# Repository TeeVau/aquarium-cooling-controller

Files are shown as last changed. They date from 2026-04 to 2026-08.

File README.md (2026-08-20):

# Aquarium Cooling Controller








ESP32 firmware for autonomous aquarium cooling with a 4-pin PWM fan, one
DS18B20 water-temperature sensor, an optional local OLED status display, MQTT
telemetry, FHEM integration, and broker-driven OTA updates.

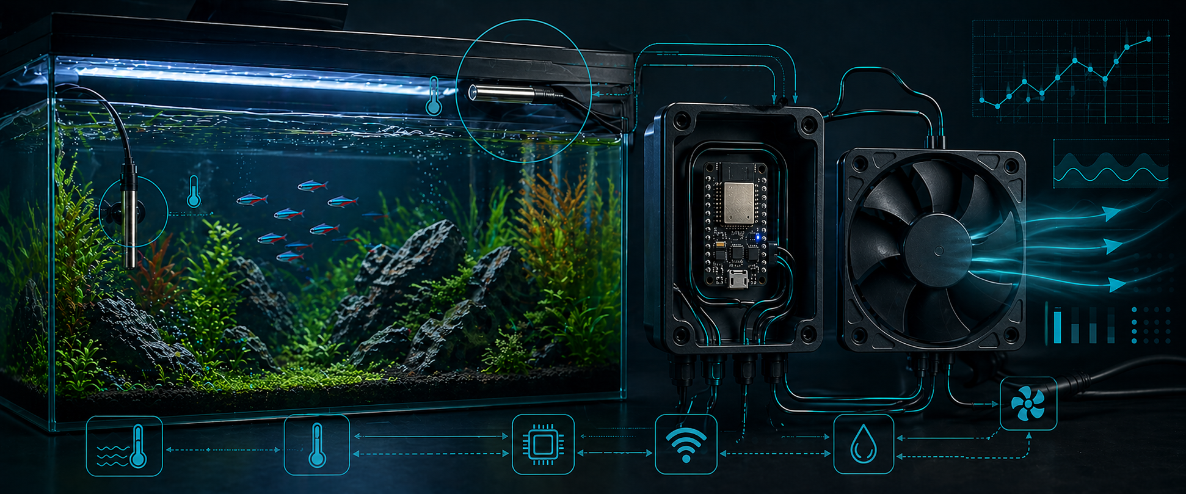
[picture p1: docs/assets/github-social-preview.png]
Aquarium Cooling Controller hero preview


## What It Does

The controller keeps cooling decisions local on the ESP32. Wi-Fi, MQTT, FHEM,
and OTA are useful for monitoring and maintenance, but cooling continues even
when the network is unavailable.

Current release: `0.3.0`.

Main capabilities:

- Water-temperature based staged fan control.
- Default target temperature: `23.0 C`.
- Default fan stages: `45%` for `fan-low`, `60%` for `fan-high`.
- Persistent target and staged-control settings in ESP32 Preferences / NVS.
- Fixed DS18B20 water-sensor assignment by ROM ID.
- Fan RPM monitoring with tach-based plausibility checks.
- Optional `0.91"` monochrome `128x32` `I2C` OLED status display for local
  water temperature and fault indication.
- MQTT telemetry for state, diagnostics, fault state, OTA state, and availability.
- Validated MQTT remote settings for target temperature, hysteresis, fan stages,
  and OTA enable/disable.
- FHEM `MQTT2_DEVICE` definition with status display, readings, set commands,
  and DBLog profile.
- BIN-only OTA update workflow through `tools/ota-upload.ps1`.

## Hardware

| Component | Purpose | Notes |
|---|---|---|
| ESP32 DevKit / ESP32-WROOM class board | Main controller | Built with FQBN `esp32:esp32:esp32` |
| Noctua NF-S12A PWM or compatible 4-pin PWM fan | Cooling actuator | 12 V fan supply |
| DS18B20 waterproof sensor | Water temperature | Current ROM: `28333844050000CB` |
| 3-pin metal circular connector | Detachable water-sensor connection | Fixed project pinout: pin 1 VCC, pin 2 GND, pin 3 DATA |
| 12 V power supply | Fan power | Common ground with ESP32 is required |
| 12 V to 5 V buck converter | ESP32 supply | Recommended for an installed controller |
| `3.3 kOhm` pull-up | 1-Wire bus | DATA to `3.3 V` |
| `3.3 kOhm` pull-up | Tach input | TACH to `3.3 V` |
| `0.91"` monochrome `128x32` `I2C` OLED (optional) | Local status view | SSD1306-compatible class, tested on GPIO32 / GPIO27 |

## Wiring

| Function | ESP32 GPIO | Notes |
|---|---:|---|
| Fan PWM | 25 | 25 kHz PWM output |
| Fan TACH | 26 | Tach input with `3.3 kOhm` pull-up |
| 1-Wire DATA | 33 | DS18B20 bus with `3.3 kOhm` pull-up |
| OLED SDA (optional) | 32 | `I2C` data line for the local status display |
| OLED SCL (optional) | 27 | `I2C` clock line for the local status display |

Fan connector reference for the installed project wiring:

| Fan Pin | Signal | Project Wire Color | Project Connection |
|---|---|---|---|
| 1 | GND | Black | Common GND |
| 2 | +12 V | Red | 12 V fan supply |
| 3 | TACH | Yellow | ESP32 GPIO26 with `3.3 kOhm` pull-up to `3.3 V` |
| 4 | PWM | Blue | ESP32 GPIO25 |

Water-temperature sensor connector:

> **Documentation follow-up:** Rework this connector section after checking
> the real plug and socket again. Add a correct, clearly oriented photo that
> shows the contact numbers and identifies the plug/socket viewing side. Until
> that review is complete, treat the table below as the intended project
> pinout and verify the actual contacts by their markings and with an unpowered
> continuity test.

| Connector Pin | Signal | Controller Connection | Sensor Wire |
|---:|---|---|---|
| 1 | VCC | `3.3 V` | `rot` |
| 2 | GND | Common GND | `gelb` |
| 3 | DATA | ESP32 GPIO33 with `3.3 kOhm` pull-up to `3.3 V` | `gruen` |

Use the pin numbers marked on the connector insert. Do not infer the numbering
from a front or rear view because the mating halves appear mirrored. The metal
connector shell is not an additional electrical contact and remains
unconnected.

Known cable colors for the currently used potted DS18B20 sensor:

| Sensor Wire | Function |
|---|---|
| `rot` | `3.3 V` |
| `gelb` | `GND` |
| `gruen` | `DATA` |

## Optional OLED Status Display

Tested display class:

```text
0.91" monochrome 128x32 I2C OLED
```

Display behavior in the current release:

- During startup, the display briefly shows `BOOT`.
- During normal operation, it shows only the current water temperature as a
  large one-decimal value.
- During an active fault, it replaces the temperature with a large `!` and the
  fault label `WATER`, `FAN`, or `BOTH`.
- The display is strictly optional. If it is missing, not detected, or later
  fails, the controller disables the display path and continues local cooling,
  MQTT, FHEM, and OTA operation normally.

## Install

Required software:

- Arduino IDE 2.x or compatible `arduino-cli`.
- ESP32 board package for Arduino.
- Arduino libraries `OneWire`, `DallasTemperature`, and `PubSubClient`.
- PowerShell on Windows for the repository helper scripts.
- Mosquitto command-line clients if you use the MQTT helper scripts directly.

Recommended ESP32 board package URL:

```text
https://raw.githubusercontent.com/espressif/arduino-esp32/gh-pages/package_esp32_index.json
```

Build from the repository root:

```powershell
powershell -ExecutionPolicy Bypass -File .\tools\build.ps1
```

The build script resolves Arduino CLI, writes board-scoped build output below
`.arduino-build/`, and exports a versioned firmware image below `bin/`.

## Configure Wi-Fi and MQTT

1. Copy `firmware/controller/network_config.local.example.h` to
   `firmware/controller/network_config.local.h`.
2. Set `AQ_WIFI_SSID`, `AQ_WIFI_PASSWORD`, `AQ_MQTT_HOST`, and optional MQTT
   credentials.
3. Keep `network_config.local.h` private; it is ignored by Git.
4. Build and flash the firmware.
5. Use the serial `network` command or FHEM readings to verify connectivity.

The committed default MQTT root topic is `aquarium/cooling`. The included FHEM
template uses the tested local root topic `aquarium_cooling`; change the root
in the FHEM file if your firmware uses another value.

## OTA Update

After a successful build, flash the installed controller over MQTT-assisted OTA:

```powershell
powershell -ExecutionPolicy Bypass -File .\tools\ota-upload.ps1
```

The OTA script:

- selects the newest versioned BIN from `bin/`,
- enables the temporary OTA maintenance window over MQTT,
- reads the controller-published upload URL,
- uploads the BIN image,
- waits for the reboot,
- verifies MQTT `availability=online`,
- verifies the reported `firmware_version`.

For normal releases, do not pass `-UploadUrl` and do not use manual HTTP upload
commands. Let the script discover the active OTA endpoint through MQTT.

## FHEM Integration

The repository includes a ready-to-import FHEM `MQTT2_DEVICE` definition:

```text
integrations/fhem/aquarium-cooling-mqtt2-device.cfg
```

The template creates readings for controller state, diagnostics, fault policy,
network status, OTA state, and remote-configuration feedback. It also exposes
validated `setList` controls for:

- `target_temp_c`
- `cooling_on_delta_c`
- `cooling_off_delta_c`
- `high_cooling_delta_c`
- `fan_low_pwm_percent`
- `fan_high_pwm_percent`
- `ota_enable`

The current field profile for the 120-liter installation uses:

```text
attr AquariumCooling event-on-change-reading .*
attr AquariumCooling event-min-interval .*:1800
attr AquariumCooling DbLogInclude water_temp_c:1800,target_temp_c:86400,fan_pwm_percent:300,controller_mode,fan_fault,alarm_code,fault_severity,fault_response,availability
```

Use the FHEM integration notes for installation and customization:

```text
integrations/fhem/README.md
```

## MQTT Topics

State topics:

| Topic suffix | Payload |
|---|---|
| `/state/water_temp_c` | Water temperature or `unavailable`, one decimal place |
| `/state/target_temp_c` | Active target temperature, one decimal place |
| `/state/cooling_on_delta_c` | Fan-on delta in Celsius |
| `/state/cooling_off_delta_c` | Fan-off delta in Celsius |
| `/state/high_cooling_delta_c` | Fan-high delta in Celsius |
| `/state/fan_low_pwm_percent` | Active low-stage PWM |
| `/state/fan_high_pwm_percent` | Active high-stage PWM |
| `/state/fan_pwm_percent` | Final commanded fan PWM |
| `/state/fan_rpm` | Measured fan speed |
| `/state/controller_mode` | `fan-off`, `fan-low`, `fan-high`, or `water-sensor-fallback` |

Status and diagnostics include RPM plausibility values, fault state,
`firmware_version`, `network_ip`, OTA state, remote-config result readings, and
`availability`.

Remote settings use `/set/...` topics with validated payloads. Invalid values
are rejected and do not overwrite persisted settings.

## Serial Service

Serial monitor settings:

```text
115200 baud
```

Commands:

| Command | Effect |
|---|---|
| `status` | Print current diagnostics |
| `target <c>` | Persist a custom target temperature |
| `default` | Reset target temperature to `23.0 C` |
| `control` | Print active staged-control settings |
| `faults` | Print fault-policy defaults |
| `network` | Print Wi-Fi/MQTT status |
| `publish` | Publish MQTT telemetry immediately |
| `ota status` | Print OTA state |
| `ota enable` | Open the temporary OTA window |
| `ota cancel` | Close the OTA window |
| `help` | Show command list |

## Repository Layout

| Path | Purpose |
|---|---|
| `firmware/controller/` | Main ESP32 controller firmware |
| `integrations/fhem/` | FHEM MQTT2 integration |
| `tools/` | Build, MQTT, OTA, and serial helper scripts |
| `docs/aquarium-cooling-controller-fsd.md` | Development FSD |
| `docs/design/` | Architecture and wiring diagrams |
| `docs/aquarium-live-tests/` | Archived field-test data |
| `docs/result fan test/` | Archived fan-characterization data |
| `bin/` | Versioned firmware binaries created by the build script |

## Troubleshooting

### Fan Does Not Run

- Verify common ground between ESP32, fan, and `12 V` supply.
- Check fan PWM on GPIO25.
- Confirm fan power is present on the 12 V line.
- Run serial `status` and inspect the active controller mode and PWM command.

### RPM Stays at Zero

- Check tach wiring on GPIO26.
- Check the `3.3 kOhm` tach pull-up to `3.3 V`.
- Confirm the fan provides a tach output.

### Water Temperature Is Unavailable

- Check DS18B20 DATA on GPIO33.
- Check the `3.3 kOhm` 1-Wire pull-up to `3.3 V`.
- Confirm the configured water-sensor ROM matches the installed sensor.
- Verify the circular connector pinout: `1 = 3.3 V/VCC`, `2 = GND`,
  `3 = DATA/GPIO33`.
- With power disconnected, check continuity through both connector halves and
  make sure their mirrored physical views have not caused the pins to be
  swapped.
- Verify sensor wiring: `rot = 3.3 V`, `gelb = GND`, `gruen = DATA`.

### OLED Stays Dark

- Verify OLED power, ground, and the `I2C` wiring on GPIO32 (`SDA`) and GPIO27
  (`SCL`).
- Confirm the module is a compatible `128x32` monochrome `I2C` OLED in the
  usual SSD1306-compatible address range.
- Check serial diagnostics for OLED detection and active display mode.
- If no compatible OLED is detected, the controller keeps running normally;
  correct the wiring or replace the display module without treating it as a
  cooling fault.

### MQTT or FHEM Does Not Update

- Run serial `network` and compare the reported root topic with the FHEM
  `readingList`.
- Confirm the broker receives `<root>/status/availability`.
- Verify the FHEM `IODev` points to the correct MQTT2 device.
- Check `remote_config_last_result`, `remote_config_last_key`, and
  `remote_config_last_detail` after sending a FHEM command.

### OTA Fails

- Run `tools/ota-upload.ps1` from the repository root.
- Confirm MQTT is online before starting OTA.
- Confirm the build produced a newer versioned BIN in `bin/`.
- Do not use `-UploadUrl` unless you are explicitly troubleshooting the raw
  HTTP endpoint.

## Project Links

- Releases: <https://github.com/TeeVau/aquarium-cooling-controller/releases>
- API documentation: <https://teevau.github.io/aquarium-cooling-controller/>
- FSD: [docs/aquarium-cooling-controller-fsd.md](docs/aquarium-cooling-controller-fsd.md)
- FHEM integration: [integrations/fhem/README.md](integrations/fhem/README.md)
- License: [GPL-3.0](LICENSE)

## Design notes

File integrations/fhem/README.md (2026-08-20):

# FHEM MQTT2 Integration

This directory contains a pasteable FHEM `MQTT2_DEVICE` definition for the
Aquarium Cooling Controller.

The checked-in configuration is based on the current running installation:

- FHEM device name: `wz_AquariumCooling`
- MQTT client / server IODev: `myBroker`
- Room: `Wohnzimmer`
- Topic root: `aquarium_cooling`
- Release: `0.3.0`

The committed template keeps portable placeholder names such as
`AquariumCooling` and `MQTT2_BROKER`; replace them with your local device names
before importing if needed.

## Files

| File | Purpose |
|---|---|
| `aquarium-cooling-mqtt2-device.cfg` | Pasteable FHEM `MQTT2_DEVICE` template with readings, status display, DBLog profile, and validated set commands |

## Installation

1. Ensure the controller publishes MQTT telemetry.
2. Create or reuse an FHEM `MQTT2_CLIENT` or `MQTT2_SERVER`.
3. Import `aquarium-cooling-mqtt2-device.cfg`.
4. Replace `MQTT2_BROKER` with your FHEM MQTT IODev name.
5. Replace `aquarium_cooling` if your firmware uses another MQTT root topic.
6. Adjust `room`, `group`, and device name to your FHEM setup.
7. Save the FHEM configuration.

## Readings

The template maps the controller's MQTT state, diagnostic, status, OTA, and
remote-configuration topics to FHEM readings.

The optional OLED is intentionally local-only in `0.3.0`; it does not add a
separate MQTT topic surface and has no impact on the FHEM integration when it
is missing or disabled.

Core readings for normal operation:

- `water_temp_c`
- `target_temp_c`
- `cooling_on_delta_c`
- `cooling_off_delta_c`
- `high_cooling_delta_c`
- `fan_low_pwm_percent`
- `fan_high_pwm_percent`
- `fan_pwm_percent`
- `fan_rpm`
- `controller_mode`
- `fan_plausible`
- `fan_fault`
- `water_sensor_ok`
- `cooling_degraded`
- `service_required`
- `alarm_code`
- `fault_severity`
- `fault_response`
- `firmware_version`
- `network_ip`
- `availability`

Maintenance and configuration readings:

- `ota_state`
- `ota_message`
- `ota_window_active`
- `ota_upload_url`
- `remote_config_last_result`
- `remote_config_last_key`
- `remote_config_last_detail`
- `remote_config_accept_count`
- `remote_config_reject_count`

Detailed RPM plausibility readings are included for visibility but are not part
of the default DBLog include list:

- `expected_rpm`
- `rpm_tolerance`
- `rpm_error`
- `plausibility_active`

## Status Display

The template sets both `stateFormat` and `devStateIcon`.

Priority order:

1. MQTT offline state.
2. Active OTA upload window.
3. Critical alarm, fan fault, or water-sensor fault.
4. Degraded or fallback cooling state.
5. Normal cooling mode.

The visible state line follows this shape:

```text
Kuehlt | Wasser 24.1 C | Ziel 24.0 C | Luefter 45 % | MQTT online
```

The template uses standard FHEM icons only.

## Set Commands

FHEM can send validated MQTT settings to the controller:

| Set command | Meaning |
|---|---|
| `target_temp_c` | Target water temperature |
| `cooling_on_delta_c` | Delta above target that starts cooling |
| `cooling_off_delta_c` | Delta below target that stops cooling |
| `high_cooling_delta_c` | Delta above target that selects `fan-high` |
| `fan_low_pwm_percent` | Fixed PWM for `fan-low` |
| `fan_high_pwm_percent` | Fixed PWM for `fan-high` |
| `ota_enable` | `true` opens, `false` cancels the OTA window |

Local control on the ESP32 remains authoritative. Invalid values are rejected
by the firmware and reported through the `remote_config_*` readings.

## DBLog Profile

The field-tested profile for the running 120-liter aquarium is:

```text
attr AquariumCooling event-on-change-reading .*
attr AquariumCooling event-min-interval .*:1800
attr AquariumCooling DbLogInclude water_temp_c:1800,target_temp_c:86400,fan_pwm_percent:300,controller_mode,fan_fault,alarm_code,fault_severity,fault_response,availability
```

This keeps long-running database growth under control while retaining the core
signals needed to understand water temperature, target, fan activity, operating
mode, fault state, and MQTT availability.

For temporary fan diagnostics, extend the DBLog include list with:

```text
fan_rpm,expected_rpm,rpm_tolerance,rpm_error,plausibility_active,fan_plausible
```

Remove those detailed readings again after the diagnostic window to keep the
long-term history compact.

## Topic Root

The template uses:

```text
aquarium_cooling
```

The firmware default is:

```text
aquarium/cooling
```

Use the serial `network` command to check which root topic your controller is
publishing, then keep the firmware and FHEM `readingList` / `setList` aligned.

## Troubleshooting

If readings do not update:

- Check that `IODev` points to the active FHEM MQTT device.
- Compare the serial `network` topic root with the FHEM topic root.
- Confirm `<root>/status/availability` is published as `online`.
- Confirm broker credentials and subscriptions.

If set commands do not apply:

- Check `remote_config_last_result`.
- Check `remote_config_last_key`.
- Check `remote_config_last_detail`.
- Verify the value is inside the firmware validation range.

If OTA does not start from FHEM:

- Set `ota_enable` to `true`.
- Watch `ota_window_active`, `ota_state`, and `ota_upload_url`.
- Prefer the repository OTA script for actual firmware uploads:

```powershell
powershell -ExecutionPolicy Bypass -File .\tools\ota-upload.ps1
```

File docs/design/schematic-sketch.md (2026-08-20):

# Schematic Sketch

This is the block-level wiring sketch for the aquarium cooling controller.

The updated version shows the central 3D-printed enclosure, the preferred rear
upper mounting position near the lighting area, and the terminal-block based
wiring concept for the fan, the detachable metal circular connector for the
water sensor, and the optional local OLED status display.

## Use in draw.io

1. Open draw.io / diagrams.net.
2. Select `Arrange -> Insert -> Advanced -> Mermaid`.
3. Paste the contents of `docs/design/schematic-sketch.mmd`.
4. Adjust layout, colors, and labels as needed.

## Notes

- This is a wiring/block sketch, not a detailed PCB schematic.
- The DS18B20 water sensor uses the 1-Wire bus on GPIO33 with a 3.3 kOhm
  pull-up to 3.3 V.
- The 3-pin metal circular water-sensor connector uses the fixed project
  pinout `1 = 3.3 V/VCC`, `2 = GND`, and `3 = DATA/GPIO33`.
- The connector depiction remains provisional until the real plug and socket
  have been rechecked and the documentation includes a correct, clearly
  oriented photo of their numbered contacts.
- Connector numbering follows the contact numbers marked on each insert; plug
  and socket views can appear mirrored. The metal shell remains unconnected.
- Fan PWM is currently assigned to GPIO25.
- Tach input is currently assigned to GPIO26 and uses a 3.3 kOhm pull-up to
  3.3 V.
- The optional local OLED status display uses `I2C` on GPIO32 (`SDA`) and
  GPIO27 (`SCL`).
- The OLED is intentionally non-critical; missing or failed display hardware
  must not affect cooling, MQTT, OTA, or fault handling.
- The installed fan wiring uses `pin 1 = black/GND`, `pin 2 = red/+12 V`,
  `pin 3 = yellow/TACH with pull-up`, and `pin 4 = blue/PWM`.
- Common ground between ESP32, fan, and 12 V fan supply is required for
  correct PWM and TACH behavior.
- Fan power stays on 12 V, while the ESP32 is supplied through a buck
  converter.
- The enclosure is modeled as the central integration point for USB-C PD board,
  5 V PSU, ESP32, the fan wiring termination, the water-sensor circular
  connector, and the optional OLED wiring.
- The mounting position is shown as above the aquarium frame on the rear side,
  near the lighting area, to keep field wiring short.

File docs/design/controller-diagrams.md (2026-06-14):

# Controller Diagrams

These Mermaid diagrams document the current controller firmware behavior in
`firmware/controller`.

The Mermaid source files below are the source of truth. The rendered SVG/PNG
artifacts are generated from the same sources for offline viewing.

The diagrams are also available as standalone `.mmd` files for draw.io /
diagrams.net imports:

- [controller-state-machine.mmd](controller-state-machine.mmd)
- [controller-system-architecture.mmd](controller-system-architecture.mmd)
- [controller-cycle-sequence.mmd](controller-cycle-sequence.mmd)

Rendering notes are available in [mermaid-rendering.md](mermaid-rendering.md).

Rendered artifacts:

- [controller-state-machine.svg](rendered/controller-state-machine.svg)
- [controller-state-machine.png](rendered/controller-state-machine.png)
- [controller-system-architecture.svg](rendered/controller-system-architecture.svg)
- [controller-system-architecture.png](rendered/controller-system-architecture.png)
- [controller-cycle-sequence.svg](rendered/controller-cycle-sequence.svg)
- [controller-cycle-sequence.png](rendered/controller-cycle-sequence.png)

## Control States

```mermaid
stateDiagram-v2
    direction LR

    state "Setup" as Setup
    state "Fan off" as FanOff
    state "Fan low" as FanLow
    state "Fan high" as FanHigh
    state "Water sensor fallback" as WaterFallback

    [*] --> Setup
    Setup --> FanOff: setup complete and water sample valid
    Setup --> WaterFallback: water sample invalid

    FanOff --> FanLow: water delta >= cooling_on_delta_c
    FanOff --> FanHigh: water delta >= high_cooling_delta_c
    FanLow --> FanOff: water delta <= cooling_off_delta_c
    FanLow --> FanHigh: water delta >= high_cooling_delta_c
    FanHigh --> FanLow: water delta < high_cooling_delta_c

    FanOff --> WaterFallback: water sample invalid
    FanLow --> WaterFallback: water sample invalid
    FanHigh --> WaterFallback: water sample invalid
    WaterFallback --> FanOff: water sample valid and water delta < cooling_on_delta_c
    WaterFallback --> FanLow: water sample valid and water delta >= cooling_on_delta_c and < high_cooling_delta_c
    WaterFallback --> FanHigh: water sample valid and water delta >= high_cooling_delta_c

    note right of FanOff
      ControlEngine mode: fan-off
      final_pwm = 0%
      target defaults to 23.0 C when invalid
    end note

    note right of FanLow
      ControlEngine mode: fan-low
      final_pwm = fan_low_pwm_percent
      default low stage = 45%
    end note

    note right of FanHigh
      ControlEngine mode: fan-high
      final_pwm = fan_high_pwm_percent
      default high stage = 60%
    end note

    note right of WaterFallback
      ControlEngine mode: water-sensor-fallback
      final_pwm = fallback PWM 40%
      fault response: water-fallback
    end note

    state "Fault policy overlay" as FaultOverlay {
        direction LR

        state "No alarm" as NoAlarm
        state "Water sensor fault" as WaterSensorFault
        state "Fan fault" as FanFault
        state "Water sensor + fan fault" as WaterAndFanFault

        [*] --> NoAlarm
        NoAlarm --> WaterSensorFault: water sample invalid
        NoAlarm --> FanFault: RPM mismatch x3

        WaterSensorFault --> NoAlarm: water sample valid
        FanFault --> NoAlarm: RPM plausible x3

        WaterSensorFault --> WaterAndFanFault: fan fault latched
        FanFault --> WaterAndFanFault: water sample invalid

        WaterAndFanFault --> FanFault: water sample valid
    }
```

## System Architecture

```mermaid
flowchart LR
  subgraph AQUA["Aquarium hardware"]
    WATER["DS18B20 water sensor<br/>ROM 28333844050000CB"]
    FAN["Noctua NF-S12A PWM fan<br/>12 V power"]
  end

  subgraph IO["ESP32 pins and electrical interfaces"]
    ONEWIRE["Shared 1-Wire bus<br/>GPIO33, 3.3 kOhm pull-up"]
    PWM["Fan PWM output<br/>GPIO25, 25 kHz"]
    TACH["Fan tach input<br/>GPIO26, 3.3 kOhm pull-up"]
  end

  subgraph LOCAL["ESP32 local autonomous control"]
    SENSOR["SensorManager<br/>2 s sample interval<br/>non-blocking DS18B20 conversion"]
    CONTROL["ControlEngine<br/>target validation<br/>water-only staged control"]
    DRIVER["FanDriver<br/>PWM command<br/>40% start boost for 2 s"]
    RPM["RpmMonitor<br/>1 s tach sample window"]
    CURVE["FanCurve<br/>expected RPM interpolation<br/>plausibility tolerance"]
    FAULTMON["FaultMonitor<br/>5 s settling<br/>3 mismatches to latch<br/>3 matches to recover"]
    POLICY["FaultPolicy<br/>alarm code<br/>severity<br/>local response"]
    PREFS["Preferences / NVS<br/>persisted target + staged control config"]
    SERIAL["Serial service console<br/>status, target, default,<br/>control, faults, network, publish"]
  end

  subgraph NET["Optional network telemetry"]
    WIFI["Wi-Fi station<br/>10 s reconnect interval"]
    MQTT["MqttTelemetry<br/>60 s full snapshot +<br/>immediate event publish<br/>availability last will"]
    BROKER["MQTT broker / FHEM<br/>state, diagnostics, status topics"]
  end

  WATER --- ONEWIRE
  ONEWIRE --> SENSOR

  SENSOR -->|ControlInputs| CONTROL
  PREFS -->|stored target + staged config| CONTROL
  SERIAL -->|target/default commands| PREFS
  SERIAL -->|diagnostic commands| CONTROL

  CONTROL -->|final PWM percent| DRIVER
  DRIVER --> PWM
  PWM --> FAN
  FAN --> TACH
  TACH --> RPM

  DRIVER -->|applied PWM| FAULTMON
  RPM -->|measured RPM| FAULTMON
  CURVE -->|expected RPM + tolerance| FAULTMON
  CONTROL -->|sensor validity + mode| POLICY
  FAULTMON -->|fan plausibility + latch| POLICY

  CONTROL --> MQTT
  FAULTMON --> MQTT
  POLICY --> MQTT
  PREFS --> MQTT
  MQTT --> WIFI
  WIFI --> BROKER

  POLICY -->|alarm, degraded cooling,<br/>service required| SERIAL
  SENSOR -->|ROMs, samples,<br/>presence pulse| SERIAL
  FAULTMON -->|RPM diagnostics| SERIAL
```

## Control Cycle Timing

```mermaid
sequenceDiagram
    autonumber
    participant Main as Controller loop
    participant Serial as Serial console
    participant Sensors as SensorManager
    participant Control as ControlEngine
    participant Fan as FanDriver
    participant RPM as RpmMonitor
    participant Fault as FaultMonitor
    participant Policy as FaultPolicy
    participant MQTT as MqttTelemetry
    participant Broker as MQTT broker

    Note over Main,MQTT: Local sensing, control, fan drive, RPM checks, and fault policy keep running without network connectivity.

    loop each Arduino loop iteration
        Main->>Serial: processSerialInput()
        Serial-->>Main: optional command effects

        Main->>Sensors: update(nowMs)
        alt cold boot or no known sensors
            Sensors->>Sensors: discover ROM IDs on shared 1-Wire bus
            Sensors->>Sensors: request temperature conversion
        else conversion pending and ready
            Sensors->>Sensors: read water temperature
        else sample interval elapsed, 2000 ms
            Sensors->>Sensors: request next conversion
        end

        Sensors-->>Main: SensorSnapshot
        Main->>Control: compute(ControlInputs)
        Control-->>Main: ControlSnapshot with fan-off/fan-low/fan-high and final PWM

        Main->>Fan: setCommandedPwmPercent(final PWM)
        Main->>Fan: update(nowMs)
        alt fan starts from 0% to nonzero PWM
            Fan-->>Main: apply 40% start boost for 2000 ms
        else steady command
            Fan-->>Main: apply commanded PWM
        end

        Main->>RPM: update(nowMs)
        RPM-->>Main: latest RPM from 1000 ms tach window

        Main->>MQTT: update(nowMs)
        alt Wi-Fi or MQTT disconnected
            MQTT->>MQTT: retry connection every 10000 ms
        else MQTT connected
            MQTT->>MQTT: mqttClient.loop()
        end

        alt diagnostics interval elapsed, 2000 ms
            Main->>Fault: evaluate(applied PWM, measured RPM, nowMs)
            Fault->>Fault: wait 5000 ms after PWM change before plausibility
            Fault-->>Main: FaultMonitorSnapshot

            Main->>Policy: evaluate(ControlSnapshot, FaultMonitorSnapshot)
            Policy-->>Main: alarm, severity, response, degraded cooling

            Main->>Serial: printDiagnostics()
            Main->>MQTT: publishTelemetry(force=false)
            alt MQTT connected and publish interval elapsed, 60000 ms
                MQTT->>Broker: publish state, diagnostics, and status topics
            else MQTT connected and event state changed
                Main->>MQTT: publishTelemetry(force=true)
                MQTT->>Broker: publish immediate controller/fault update
            else not connected or interval not elapsed
                MQTT-->>Main: skip telemetry publish
            end
        else diagnostics interval not elapsed
            Main-->>Main: return quickly to keep loop responsive
        end
    end
```

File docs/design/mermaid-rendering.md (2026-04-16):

# Mermaid Rendering

The controller diagrams are plain Mermaid source files. GitHub renders the
embedded diagrams in `controller-diagrams.md` automatically, and Mermaid CLI can
render the standalone `.mmd` files to SVG or PNG artifacts.

## Install Mermaid CLI

Mermaid CLI provides the `mmdc` command. It requires Node.js and npm.

### Option 1: System install

Install Node.js LTS from the official Node.js download page, then open a new
PowerShell window and run:

```powershell
npm install -g @mermaid-js/mermaid-cli
mmdc --version
```

### Option 2: One-off use without global install

After Node.js is installed, render one diagram without installing `mmdc`
globally:

```powershell
npx -p @mermaid-js/mermaid-cli mmdc -i docs\design\controller-state-machine.mmd -o docs\design\rendered\controller-state-machine.svg
```

### Option 3: Docker

If Docker is available, use the official Mermaid CLI container image:

```powershell
docker run --rm -v "${PWD}:/data" ghcr.io/mermaid-js/mermaid-cli/mermaid-cli -i /data/docs/design/controller-state-machine.mmd -o /data/docs/design/rendered/controller-state-machine.svg
```

## Render Project Diagrams

Once `mmdc` is available in `PATH`, render all controller diagrams:

```powershell
powershell -ExecutionPolicy Bypass -File .\tools\render-mermaid.ps1
```

This creates SVG and PNG files in:

```text
docs\design\rendered\
```

Render only SVG:

```powershell
powershell -ExecutionPolicy Bypass -File .\tools\render-mermaid.ps1 -Format svg
```

## Render Online

If local Node.js or `mmdc` is not available, the project also includes an online
renderer helper that uses `mermaid.ink`:

```powershell
powershell -ExecutionPolicy Bypass -File .\tools\render-mermaid-online.ps1
```

This also creates SVG and PNG files in:

```text
docs\design\rendered\
```

## Validate by Rendering

Mermaid CLI exits with a nonzero status when a diagram cannot be parsed or
rendered. For these diagrams, a successful run of `tools/render-mermaid.ps1`
acts as the local render check.

The online helper similarly fails if a generated artifact is empty or the HTTP
request fails.

For PNG output, the helper downloads the online raster output and converts it to
a real PNG locally, so the saved file has the expected PNG signature.

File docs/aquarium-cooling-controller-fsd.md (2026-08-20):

# Aquarium Cooling Controller - Functional Specification Document (FSD)

## 1. System Overview

### Purpose

The Aquarium Cooling Controller is an ESP32-based embedded system that reduces
aquarium water temperature through evaporative cooling with a 4-pin PWM fan.
The system shall keep all critical temperature-control functions local to the
ESP32 and use Wi-Fi/MQTT only for observability, OTA firmware delivery, and
non-critical remote configuration.

### Problem Statement

The covered aquarium water temperature is influenced by multiple heat sources
and boundary conditions. Relevant contributors include warm air trapped under
the lid by the LED lighting, waste heat from the external filter that is
coupled back into the circulating water, and the ambient room temperature.
These factors require a cooling strategy that is quiet, reliable, and
autonomous even when the network is unavailable. Before the production
controller is finalized, the specific fan must be characterized so that the
firmware can use a measured PWM-to-RPM curve for low-noise operation and
plausibility-based fault detection.

### Goals

- Provide local autonomous cooling based on water temperature.
- Keep water temperature within an aquarium-safe band around the configured
  target rather than chasing fine-grained sub-degree precision.
- Provide an optional local OLED temperature readout without making controller
  operation depend on the display.
- Minimize unnecessary fan runtime through a simple hysteresis-based water
  controller with fixed low and high cooling stages.
- Characterize the selected fan automatically before production deployment.
- Persist target temperature and supported controller settings across reboot.
- Detect implausible fan behavior using measured curve data and tolerance logic.
- Expose telemetry and selected configuration over MQTT without making cooling
  dependent on MQTT or Wi-Fi.
- Support OTA firmware updates via the ESP32 WLAN client without compromising
  autonomous cooling behavior.

### Non-Goals

- Heating control
- Local button UI
- Multi-page or rotating local display content
- Simultaneous display of multiple operating values on the OLED
- Cloud-first control logic
- MQTT participation during the fan-characterization sketch
- Complex cloud integrations beyond local MQTT messaging

### High-Level System Flow

1. The ESP32 boots, initializes hardware, and loads persisted configuration.
2. In characterization mode, the ESP32 runs an automatic fan test and prints
   reusable curve data via serial.
3. In production mode, the ESP32 reads DS18B20 water temperature.
4. The controller computes the fan state from water temperature relative to the
   configured target, using hysteresis and fixed low/high PWM cooling stages.
5. The ESP32 drives the fan, measures tachometer RPM, and evaluates
   plausibility above the stable operating range.
6. Wi-Fi and MQTT publish telemetry, and a manually enabled OTA maintenance
   mode can accept a local firmware binary upload when service is required.
7. When present, an optional OLED mirrors one local operator-facing state at a
   time: boot, normal water temperature, or an active fault indication.
8. Faults are latched and reported without stopping local autonomous control
   unless a defined fault policy requires a safe fallback state.

## 2. System Architecture

### 2.1 Logical Architecture

The system is partitioned into critical local functions and non-critical
networked functions.

Critical local functions:

- Temperature acquisition from DS18B20 sensors
- Loading and validating persisted configuration
- Water-temperature control logic
- Hysteresis state management
- PWM fan actuation
- Tachometer-based RPM measurement
- Fan plausibility evaluation
- Fault-state handling

Non-critical functions:

- Optional OLED status display
- Wi-Fi connection management
- MQTT publish/subscribe
- Temporarily enabled OTA upload service
- Remote parameter updates
- Diagnostic telemetry

Runtime interactions:

1. Sensor manager provides water temperature samples.
2. Config manager provides validated persisted settings.
3. Control engine computes the water-driven control state and corresponding
   staged PWM command.
4. Fan driver applies PWM and exposes commanded duty cycle.
5. RPM monitor measures actual fan speed.
6. Fault monitor compares measured RPM to the expected curve.
7. Telemetry layer publishes state and accepts approved remote settings.
8. OLED status display renders the current visible local display state when a
   compatible display is present and otherwise remains disabled.
9. The OTA upload service remains disabled during normal operation and, after
   explicit service activation, accepts a single local firmware binary upload
   for validation and activation.

### 2.2 Hardware / Platform Architecture

| Element | Selection | Role |
|---|---|---|
| MCU | ESP32-WROOM-32E on ESP32-DevKitC V4 | Main controller |
| Fan | 120 mm 4-pin PWM fan, e.g. Noctua NF-S12A PWM | Cooling actuator |
| Water sensor | DS18B20 | Primary control variable |
| Power input | USB-C PD trigger requesting 12 V | Single-cable power source |
| 5 V PSU | Switched-mode 12 V to 5 V supply / buck converter | Controller supply |
| OLED display (optional) | `0.91"` monochrome `128x32` `I2C` OLED | Non-critical local status readout |
| 1-Wire pull-up | 3.3 kOhm to 3.3 V | Bus biasing in the verified bench setup |
| Tach pull-up | 3.3 kOhm to 3.3 V | Open-collector tach input biasing in the verified bench setup |
| Water-sensor connector | 3-pin metal circular connector | Detachable DS18B20 field connection with fixed project pinout |
| Terminal blocks | Fan and internal wiring connections | Field and enclosure wiring termination |

Pin assignment:

| Signal | ESP32 GPIO | Notes |
|---|---:|---|
| Fan PWM | 25 | 25 kHz PWM output |
| Fan TACH | 26 | Interrupt-capable input with 3.3 kOhm pull-up to 3.3 V |
| 1-Wire bus | 33 | DS18B20 bus for the water sensor |
| OLED SDA (optional) | 32 | `I2C` data line for the optional OLED |
| OLED SCL (optional) | 27 | `I2C` clock line for the optional OLED |

Fan connector pinout for the installed project wiring:

| Fan Pin | Signal | Project Wire Color | Project Connection |
|---|---|---|---|
| 1 | GND | Black | Common GND |
| 2 | +12 V | Red | 12 V fan supply from PD rail |
| 3 | TACH | Yellow | ESP32 GPIO26 tach input with 3.3 kOhm pull-up to 3.3 V |
| 4 | PWM | Blue | ESP32 GPIO25 PWM output via interface stage |

Water-temperature sensor connector pinout:

> **Documentation status - open:** This connector documentation must be
> reviewed against the real plug and socket and supplemented with a correct,
> clearly oriented photo showing the contact numbers and viewing side. The
> pinout below remains the intended project mapping until that hardware-backed
> documentation review is complete.

| Connector Pin | Signal | Controller-Side Connection | Current Sensor Wire |
|---:|---|---|---|
| 1 | VCC | 3.3 V | Red (`rot`) |
| 2 | GND | Common GND | Yellow (`gelb`) |
| 3 | DATA | ESP32 GPIO33 with 3.3 kOhm pull-up to 3.3 V | Green (`gruen`) |

The numbered contacts marked on the connector insert define the pinout on both
mating halves. Visual left-to-right positions shall not be used because front
and rear views, as well as plug and socket, appear mirrored. The metal shell is
not part of the three-contact signal pinout and shall remain electrically
unconnected unless a later documented shielding design explicitly assigns it.

Hardware constraints:

- Fan supply shall remain at 12 V while the ESP32 logic remains at 3.3 V/5 V.
- Common ground between fan power and ESP32 shall be mandatory.
- The final PWM output stage must be electrically compatible with 4-pin PC fan
  PWM input requirements.
- The tach signal shall be treated as open-collector/open-drain style feedback.
- The water sensor shall be connected or disconnected only while controller
  power is off.
- The 1-Wire pull-up shall remain on the controller side between DATA/pin 3 and
  3.3 V so it remains present when the sensor is unplugged.

### 2.3 Software Architecture

Planned software modules:

| Module | Responsibility |
|---|---|
| `boot/init` | Startup sequencing and hardware initialization |
| `config` | Preferences/NVS persistence and validation |
| `fan_characterization` | Automated standalone fan test sketch |
| `sensor_manager` | DS18B20 discovery, ROM-ID assignment, sample acquisition |
| `control_engine` | Water-only hysteresis control and staged PWM command selection |
| `fan_driver` | PWM output handling and start-boost support |
| `rpm_monitor` | Tach pulse counting and RPM calculation |
| `fault_monitor` | Plausibility checking, debounce, fault latching |
| `fault_policy` | Alarm classification, severity, and local fault response |
| `oled_status_display` | Optional local OLED rendering for boot, temperature, and fault indication |
| `telemetry` | Wi-Fi, MQTT publish/subscribe, diagnostics |
| `ota_upload_server` | Temporary BIN-only OTA upload endpoint, image validation, update handoff |

Boot sequence:

1. Initialize serial diagnostics and hardware GPIO.
2. Initialize PWM output and tach interrupt.
3. Load persisted configuration from Preferences/NVS.
4. Validate configuration and fall back to defaults if invalid.
5. Start local control and safety monitoring.
6. Attempt Wi-Fi/MQTT connectivity after local control is operational.
7. Keep OTA upload functionality disabled until local control startup has
   completed and an operator explicitly enables the OTA maintenance window.

Persistence model:

- Storage backend: ESP32 Preferences / NVS
- Current implementation persists the target temperature
- Invalid persisted target values shall be cleared and replaced with the
  default target temperature
- The simplified control strategy shall persist target temperature and the
  supported remote-configurable controller settings:
  `cooling_on_delta_c`, `cooling_off_delta_c`, `high_cooling_delta_c`,
  `fan_low_pwm_percent`, and `fan_high_pwm_percent`
- Invalid or inconsistent persisted controller values shall be cleared and
  replaced with documented defaults
- Sensor role mapping shall use the water-sensor DS18B20 ROM ID rather than bus
  order

Update model:

- Characterization sketch is a standalone firmware artifact.
- Production firmware is a separate artifact that reuses measured fan-curve
  data.
- Production firmware releases shall use Semantic Versioning 2.0.0
  (`MAJOR.MINOR.PATCH`) as defined by <https://semver.org/>.
- Firmware release history shall be maintained in a `CHANGELOG.md` file using
  the Keep a Changelog format defined by <https://keepachangelog.com/>.
- Production firmware shall support OTA updates through a manually enabled,
  temporary local upload endpoint on the ESP32.
- OTA shall use the compiled firmware `.bin` image directly. ZIP archives,
  manifest files, and external update polling are not part of the initial OTA
  workflow.
- The OTA upload endpoint shall not require a password or token. Protection is
  provided by keeping the endpoint disabled by default, limiting the active
  upload window, accepting one upload attempt per activation, and validating the
  received firmware image.
- OTA shall be treated as a non-critical service and shall not block local
  cooling startup.
- OTA failures shall leave the device on the previously working firmware.
- For the OLED feature workstream, OTA-deployable development builds used
  versions starting at `0.2.1` and increasing monotonically from the installed
  `0.2.0` baseline so the broker-driven OTA workflow could validate them as
  newer.
- The completed OLED feature set is prepared for release as version `0.3.0`
  after implementation and basic real-hardware verification.

## 3. Implementation Phases

### 3.1 Phase 1 - Fan Characterization Foundation

Scope:

- Implement standalone automatic fan test sketch
- Detect safe start PWM from standstill
- Measure increasing and decreasing PWM-to-RPM curves
- Detect minimum hold PWM while the fan is already spinning
- Print reusable serial output for later firmware integration

Deliverables:

- Compilable ESP32 Arduino characterization sketch
- Human-readable serial log
- Tabular PWM/RPM output
- C-array initializer for measured curve points
- Bench log and summarized characterization result stored in project docs

Exit criteria:

- Sketch compiles for ESP32 Arduino
- Sketch runs without manual serial commands
- Start PWM is reported
- Hold PWM is reported
- Up and down curves are printed
- Measured data is reusable in later firmware
- Latest verified characterization run is archived in project documentation

Dependencies:

- Selected physical fan available
- Tach signal electrically readable
- Stable 12 V power path

### 3.2 Phase 2 - Autonomous Local Cooling Controller

Scope:

- Integrate DS18B20 water temperature sensing
- Implement local hysteresis-based staged water cooling control using persisted
  configuration
- Apply fixed low/high cooling stages and optional start-boost support
- Add fan plausibility checking using measured curve interpolation
- Introduce fault handling for fan and water-sensor failures

Deliverables:

- Production-oriented local control firmware
- Persistent configuration storage
- Deterministic control loop
- Fault and diagnostics model

Exit criteria:

- Controller cools without Wi-Fi or MQTT
- Target temperature survives reboot
- Sensor roles remain stable by ROM ID
- Fan fault detection works above stable operating range

Dependencies:

- Phase 1 fan characterization results
- Installed DS18B20 sensors
- Finalized local fault-reaction policy for sensor and fan faults

### 3.3 Phase 3 - Networked Observability and Remote Configuration

Scope:

- Add Wi-Fi connectivity
- Publish telemetry and fault state over MQTT
- Add manually enabled BIN-only OTA firmware upload capability over the WLAN
  client
- Accept validated remote configuration updates for the supported simplified
  control surface
- Use a slower regular MQTT publish cadence suitable for a thermally sluggish
  120-liter aquarium while still surfacing important state changes immediately
- Keep local control fully autonomous during network outages

Current implementation note: Wi-Fi/MQTT publish telemetry and network
diagnostics are implemented and verified against the local MQTT broker.
Manually enabled BIN-only OTA upload is implemented and now also verified
through the repository `tools/ota-upload.ps1` workflow on the fully wired
controller hardware, including MQTT-triggered OTA enable, MQTT publication of
the active upload endpoint, HTTP upload of the newest versioned BIN from
`bin/`, and post-reboot verification of `availability=online` plus the target
`firmware_version`. The current production firmware uses the revised
water-driven control architecture; the target-state FSD extends that surface to
staged cooling and a broader validated MQTT control surface. The checked-in
FHEM `MQTT2_DEVICE` integration shall be updated in lockstep with the
documented topic set.

Deliverables:

- MQTT topic implementation
- BIN-only OTA upload workflow
- Telemetry and status publishing with hybrid periodic/event-driven behavior
- FHEM monitoring integration for current MQTT telemetry
- Validated remote settings workflow

Exit criteria:

- MQTT publishes required state and diagnostics with a 60-second baseline
  snapshot cadence plus immediate publishes for controller/fault changes
- OTA firmware image can be uploaded locally, validated, and applied over Wi-Fi
- Approved remote settings are persisted
- Network loss does not interrupt cooling autonomy

Dependencies:

- Phase 2 production controller complete
- MQTT broker and Wi-Fi credentials available

### 3.4 Phase 4 - Optional Local OLED Status Display

Scope:

- Add optional `0.91"` monochrome `128x32` `I2C` OLED support as a strictly
  non-critical local display path
- Introduce a short `BOOT` start view before the first stable runtime display
  state is known
- Show only the current water temperature as a large one-decimal number during
  normal operation
- Replace the normal temperature view with a large `!` plus a small fault text
  of `WATER`, `FAN`, or `BOTH` when an active alarm is present
- Keep the display fully disabled when no compatible OLED is detected

Bring-up sequence:

- Phase 4a: implement the optional display path and fail-open behavior without
  requiring the real display hardware to be connected
- Phase 4b: connect the real OLED module and complete the first hardware
  verification on the installed controller

Deliverables:

- Optional OLED display module integrated into production firmware
- Defined display-state behavior for boot, normal operation, and active faults
- Non-blocking no-display detection and disable path
- Hardware verification notes for the real connected OLED

Exit criteria:

- Firmware continues to boot and regulate normally with no OLED connected
- With a connected OLED, `BOOT`, temperature, and fault screens render as
  specified
- No display state can block or degrade local cooling, MQTT, or OTA behavior

Dependencies:

- Phase 2 production controller complete
- Phase 3 OTA workflow available for iterative development starting at `0.2.1`
- Access to a compatible OLED module for Phase 4b hardware verification

## 4. Functional Requirements

### 4.1 Functional Requirements (FR)

#### Phase 1 - Characterization

- FR-1.1 [Must]: The system shall provide a standalone fan-characterization
  firmware artifact that does not require Wi-Fi or MQTT.
- FR-1.2 [Must]: The characterization sketch shall automatically search the
  minimum PWM at which the fan starts reliably from standstill.
- FR-1.3 [Must]: The characterization sketch shall measure the increasing
  PWM-to-RPM curve from the detected start PWM up to 100% PWM.
- FR-1.4 [Must]: The characterization sketch shall measure the decreasing
  PWM-to-RPM curve from 100% PWM down to 0% PWM.
- FR-1.5 [Must]: The characterization sketch shall determine the minimum hold
  PWM while the fan is already spinning.
- FR-1.6 [Must]: The characterization sketch shall print a progress log, a
  readable curve table, and a machine-usable C-array initializer.

#### Phase 2 - Local Autonomous Cooling

- FR-2.1 [Must]: The production controller shall read water temperature from a
  dedicated DS18B20 sensor identified by ROM ID.
- FR-2.2 [Must]: The production controller shall compute the primary cooling
  state from water temperature relative to the configured target temperature.
- FR-2.3 [Must]: The production controller shall switch from `fan-off` to
  `fan-low` when water temperature reaches the configured upper hysteresis
  threshold relative to target.
- FR-2.4 [Must]: The production controller shall switch from `fan-low` to
  `fan-high` when water temperature reaches the configured high-cooling delta
  threshold relative to target.
- FR-2.5 [Must]: The production controller shall switch from `fan-high` back to
  `fan-low` when water temperature falls below the configured high-cooling delta
  threshold and shall switch from `fan-low` back to `fan-off` when water
  temperature reaches the configured lower hysteresis threshold relative to
  target.
- FR-2.6 [Should]: The production controller should apply start-boost behavior
  when needed to improve reliable low-speed fan startup.
- FR-2.7 [Must]: The production controller shall drive the fan through a PWM
  output suitable for a 4-pin PWM fan.
- FR-2.8 [Must]: The production controller shall measure fan RPM from the tach
  signal using pulse counting.
- FR-2.9 [Must]: The production controller shall persist target temperature and
  all supported remote-configurable controller settings in Preferences/NVS.
- FR-2.10 [Must]: The production controller shall load persisted configuration
  at boot, validate it, and apply defaults if stored values are invalid.
- FR-2.11 [Must]: The production controller shall continue local cooling
  operation when Wi-Fi or MQTT is unavailable.
- FR-2.12 [Must]: The DS18B20 water-temperature sensor shall be detachable
  through a 3-pin metal circular connector with pin 1 assigned to 3.3 V/VCC,
  pin 2 assigned to GND, and pin 3 assigned to DATA on ESP32 GPIO33.

#### Phase 2 - Fault Handling

- FR-3.1 [Must]: The production controller shall estimate expected fan RPM from
  the measured fan curve using linear interpolation between neighboring points.
- FR-3.2 [Must]: The production controller shall evaluate fan plausibility only
  above the minimum stable operating PWM and after a settling delay following
  PWM changes.
- FR-3.3 [Must]: The production controller shall confirm fan fault state only
  after multiple consecutive plausibility mismatches.
- FR-3.4 [Must]: The production controller shall expose diagnostics including
  expected RPM, measured RPM, RPM error, plausibility state, and fan-fault
  state.
- FR-3.5 [Must]: The production controller shall enter a defined fallback fault
  behavior when the water-temperature sensor is unavailable.
- FR-3.6 [Should]: The production controller should support recovery from a fan
  plausibility fault only after multiple consecutive valid matches.

#### Phase 3 - MQTT Integration

- FR-4.1 [Must]: The production controller shall publish water temperature, fan
  PWM, fan RPM, target temperature, active staged-control parameters,
  controller mode, and fault status over MQTT as a regular full snapshot.
- FR-4.2 [Must]: The production controller shall accept validated remote
  updates for target temperature and all supported normal controller parameters
  over MQTT, validate each requested change against the complete resulting
  configuration, reject invalid payloads without overwriting valid persisted
  settings, and report the result through diagnostics or MQTT status topics.
- FR-4.3 [Should]: The production controller should support a manual override
  mode for service or testing with explicit validation and clear state
  reporting.
- FR-4.4 [Must]: The production controller shall support manual BIN-only OTA
  firmware upload over the WLAN client through a temporary ESP32-hosted upload
  endpoint.
- FR-4.5 [Must]: The production controller shall start OTA upload activity only
  after local cooling control is already active and an operator explicitly
  enables the OTA maintenance window.
- FR-4.6 [Must]: The production controller shall validate the uploaded firmware
  image size, ESP32 image validity, firmware release identity, and update result
  before activating the uploaded firmware image.
- FR-4.7 [Must]: The production controller shall preserve the last working
  firmware if OTA upload, validation, or activation fails.
- FR-4.8 [Should]: The production controller should publish OTA state and last
  update result through diagnostics or MQTT status topics.
- FR-4.9 [Should]: The repository should provide a local home-automation
  integration definition for the current MQTT telemetry surface and validated
  remote settings. The current FHEM `MQTT2_DEVICE` definition covers the
  documented readings plus the supported remote set commands.
- FR-4.10 [Must]: The production controller shall use a default regular MQTT
  full-snapshot interval of 60 seconds for the 120-liter production aquarium
  profile.
- FR-4.11 [Must]: The production controller shall publish an immediate extra
  MQTT snapshot when controller mode, commanded fan PWM, fan fault, alarm code,
  fault severity, fault response, water-sensor health, degraded-cooling state,
  or service-required state changes.

#### Phase 4 - Optional Local OLED Display

- FR-5.1 [Must]: The production controller shall support an optional local
  `I2C` OLED status display using a `0.91"` monochrome `128x32` display class.
- FR-5.2 [Must]: During normal operation, the display shall show only the
  current water temperature as a large one-decimal numeric value.
- FR-5.3 [Must]: During startup, before the first stable runtime display state
  is known, the display shall show `BOOT`.
- FR-5.4 [Must]: When an active fault alarm is present, the display shall
  replace the normal temperature view with a large `!` and a small fault text.
- FR-5.5 [Must]: The display fault texts shall be `WATER` for a water-sensor
  fault, `FAN` for a fan fault, and `BOTH` for a combined water-sensor and fan
  fault.
- FR-5.6 [Must]: The OLED v1 implementation shall not add buttons, page
  switching, rotating content, simultaneous multi-value display, or fan-RPM
  display.
- FR-5.7 [Must]: Missing, non-initializable, or later failing display hardware
  shall not affect sensing, control, fault handling, MQTT, OTA, or the normal
  controller boot path.
- FR-5.8 [Should]: The display should update only when the visible rendered
  content changes.
- FR-5.9 [Must]: If no compatible OLED is detected on the configured `I2C`
  bus, the firmware shall disable the display path and continue normal
  controller operation.
- FR-5.10 [Should]: The firmware should expose display-availability state
  through serial diagnostics so bring-up and later field support remain
  understandable.

### 4.2 Non-Functional Requirements (NFR)

- NFR-1.1 [Must]: Critical cooling logic must execute locally on the ESP32 and
  must not depend on network connectivity.
- NFR-1.2 [Must]: The system must prefer quiet fan behavior over maximum
  cooling performance whenever temperature safety is maintained.
- NFR-1.3 [Must]: The system must retain persisted configuration across reboot
  and across temporary Wi-Fi/MQTT outages.
- NFR-1.4 [Must]: The system must use deterministic control logic suitable for
  an embedded real-time-ish control loop.
- NFR-1.5 [Must]: The system must avoid unnecessary dynamic memory allocation in
  critical runtime paths.
- NFR-1.6 [Should]: The system should separate critical control logic from
  communication logic for maintainability and fault isolation.
- NFR-1.7 [Must]: The system must provide sufficient diagnostics to distinguish
  sensor fault, fan fault, and network fault conditions.
- NFR-1.8 [Should]: The system should boot into a valid local control state
  before attempting network services.
- NFR-1.9 [Must]: The characterization sketch must run fully automatically with
  no manual serial commands.
- NFR-1.10 [Must]: OTA update handling must not delay or block the start of
  local autonomous cooling beyond normal network-service initialization.
- NFR-1.11 [Must]: OTA update integrity must be verifiable before a new
  firmware image is activated through ESP32 image validation and release
  identity checks.
- NFR-1.12 [Must]: Production firmware version numbers shall follow Semantic
  Versioning 2.0.0 as `MAJOR.MINOR.PATCH`, with optional pre-release or build
  metadata only when it conforms to the SemVer specification.
- NFR-1.12a [Must]: OLED feature development builds intended for OTA testing
  shall use monotonically increasing versions starting at `0.2.1` above the
  currently installed `0.2.0` baseline, and the intended completed feature
  release shall use version `0.3.0`.
- NFR-1.13 [Must]: The repository shall maintain release history in
  `CHANGELOG.md` using the Keep a Changelog structure, including an
  `Unreleased` section and grouped notable changes for each released version.
- NFR-1.14 [Should]: Production telemetry and FHEM long-running history should
  remain operationally useful without producing unnecessary repeated data for
  the thermally sluggish 120-liter aquarium.

### 4.3 Constraints

- System only cools; it does not provide heating.
- The optional local OLED interface is display-only and shall not introduce a
  local input path.
- The OLED v1 scope shall show only one operator-facing item at a time.
- Water-sensor identification shall not depend on DS18B20 bus order.
- The final PWM electrical interface must be validated with the selected fan.
- Fan plausibility tolerance and confirmed fan-fault reaction are not yet fully
  finalized.
- Low-PWM regions may require wider tolerance or exclusion from plausibility
  checking.
- The revised control strategy intentionally allows wider water-temperature
  movement around target than the previous fine-grained PWM ramp, provided the
  aquarium remains within the accepted safety band.

## 5. Risks, Assumptions & Dependencies

### Technical Risks

| Risk | Likelihood | Impact | Mitigation |
|---|---|---|---|
| Fan PWM electrical interface is not fully compatible with the selected fan | Medium | High | Validate prototype waveform and startup behavior before production |
| Low-PWM tach readings are unstable and trigger false faults | High | Medium | Exclude unstable region or widen tolerance below stable PWM |
| Under-lid airflow differs from free-air characterization | Medium | Medium | Verify curve once in free air and again in installed configuration |
| Fixed low PWM may be too weak during seasonal heat peaks | Medium | Medium | Validate the staged controller in summer-like conditions and tune the second stage if measurements justify it |
| DS18B20 bus or role mapping errors misidentify the water sensor | Low | High | Assign the water sensor by ROM ID and verify mapping at commissioning |
| Fault reaction for confirmed fan fault remains underspecified | Medium | High | Finalize explicit reaction before production release |
| Unauthenticated OTA upload window is reachable by other clients on the local network | Low | High | Keep OTA disabled by default, require explicit service activation, limit the upload window, accept one upload attempt, and validate firmware identity before activation |
| Initial OLED wiring, address selection, or module-compatibility errors delay first hardware verification | Medium | Medium | Implement and OTA-test the display path with strict fail-open behavior first, then confirm wiring, address detection, and runtime rendering on the connected OLED |
| `I2C` OLED detection or runtime errors interfere with startup | Medium | High | Keep OLED initialization optional, time-bounded, and non-blocking; disable the display path on failure |
| Mirrored connector views or ignored contact markings swap VCC, GND, and DATA during assembly | Medium | High | Use only the insert-marked pin numbers, wire both halves to the fixed project pinout, and perform an unpowered continuity test before connecting the ESP32 or sensor |

### Assumptions

- The selected fan provides two tach pulses per revolution, matching the test
  sketch assumption.
- A fixed initial plausibility tolerance around +/-12% is a suitable starting
  point until measured tuning data is available (assumed).
- The aquarium lid has both a dedicated fan opening and a separate air outlet,
  allowing effective airflow (assumed from project notes).
- Water temperature is the only required closed-loop control input for the
  simplified production strategy (assumed from the logged aquarium trials).
- OTA uploads will be performed from a trusted client on the same local network
  during a short, explicitly enabled maintenance window (assumed).
- A 60-second regular MQTT snapshot interval is sufficient for the 120-liter
  aquarium because the water mass changes thermally much more slowly than the
  local 2-second control loop (assumed).
- A compatible `0.91"` `128x32` `I2C` OLED has been connected on GPIO32/GPIO27
  and basic hardware verification of the normal temperature view has been
  completed in the installed controller.

### External Dependencies

- ESP32 Arduino framework
- Preferences library
- OneWire library
- DallasTemperature library
- WiFi library
- MQTT client library such as PubSubClient or equivalent
- OTA-capable update library or ESP32 OTA support compatible with the chosen
  Arduino framework
- Semantic Versioning 2.0.0 release numbering rules
- Keep a Changelog release-history format
- USB-C PD trigger hardware
- Selected 4-pin PWM fan and DS18B20 water sensor

### Environmental Constraints

- Covered aquarium environment with moisture and heat near the lid
- Single-cable compact power delivery preferred
- Low audible noise prioritized over maximum airflow

## 6. Interface Specifications

### 6.1 External Interfaces

#### Hardware Interfaces

| Interface | Direction | Description |
|---|---|---|
| 4-pin fan PWM | ESP32 -> fan | Speed command at nominal 25 kHz PWM |
| 4-pin fan tach | fan -> ESP32 | Pulse feedback for RPM measurement |
| 1-Wire water-sensor connector | bidirectional | Detachable DS18B20 interface: pin 1 = 3.3 V/VCC, pin 2 = GND, pin 3 = DATA/GPIO33 |
| `I2C` OLED (optional) | ESP32 -> display | Non-critical local status display for boot, temperature, and active faults |
| USB serial | ESP32 -> host | Diagnostics and characterization output |
| Wi-Fi | ESP32 <-> LAN | Production telemetry transport |
| MQTT | ESP32 <-> broker | Production state publish and remote set commands |
| OTA upload endpoint | host -> ESP32 | Temporary local upload of one compiled firmware `.bin` image over Wi-Fi |

#### MQTT Topic Proposal

Committed defaults use the root `aquarium/cooling`. The field-validated local
installation uses the override root `aquarium_cooling` from the ignored local
network configuration file.

| Topic | Direction | Purpose |
|---|---|---|
| `aquarium/cooling/state/water_temp_c` | publish | Water temperature, rounded to one decimal place at the output boundary |
| `aquarium/cooling/state/fan_pwm_percent` | publish | Commanded fan PWM |
| `aquarium/cooling/state/fan_rpm` | publish | Measured fan RPM |
| `aquarium/cooling/state/target_temp_c` | publish | Active target temperature, rounded to one decimal place at the output boundary |
| `aquarium/cooling/state/cooling_on_delta_c` | publish | Active upper hysteresis delta relative to target |
| `aquarium/cooling/state/cooling_off_delta_c` | publish | Active lower hysteresis delta relative to target |
| `aquarium/cooling/state/high_cooling_delta_c` | publish | Active delta relative to target that enters `fan-high` |
| `aquarium/cooling/state/fan_low_pwm_percent` | publish | Active fixed PWM used for `fan-low` |
| `aquarium/cooling/state/fan_high_pwm_percent` | publish | Active fixed PWM used for `fan-high` |
| `aquarium/cooling/state/controller_mode` | publish | Active control state such as `fan-off`, `fan-low`, `fan-high`, or `water-sensor-fallback` |
| `aquarium/cooling/diagnostic/expected_rpm` | publish | Interpolated expected RPM |
| `aquarium/cooling/diagnostic/rpm_tolerance` | publish | Current RPM tolerance |
| `aquarium/cooling/diagnostic/rpm_error` | publish | Measured minus expected RPM |
| `aquarium/cooling/diagnostic/plausibility_active` | publish | Whether fan plausibility is currently evaluated |
| `aquarium/cooling/diagnostic/remote_config_accept_count` | publish | Accepted remote-config command count |
| `aquarium/cooling/diagnostic/remote_config_reject_count` | publish | Rejected remote-config command count |
| `aquarium/cooling/status/fan_plausible` | publish | Plausibility state |
| `aquarium/cooling/status/fan_fault` | publish | Latched fan fault |
| `aquarium/cooling/status/water_sensor_ok` | publish | Water sensor health |
| `aquarium/cooling/status/cooling_degraded` | publish | Whether cooling effectiveness is degraded |
| `aquarium/cooling/status/service_required` | publish | Whether operator action is required |
| `aquarium/cooling/status/alarm_code` | publish | Fault summary |
| `aquarium/cooling/status/fault_severity` | publish | Fault severity |
| `aquarium/cooling/status/fault_response` | publish | Local fault response |
| `aquarium/cooling/status/firmware_version` | publish | Running firmware version |
| `aquarium/cooling/status/network_ip` | publish | Current Wi-Fi station IP or `unavailable` |
| `aquarium/cooling/status/ota_state` | publish | Current OTA upload state |
| `aquarium/cooling/status/ota_message` | publish | Latest OTA status message |
| `aquarium/cooling/status/ota_window_active` | publish | Whether the OTA upload window is currently active |
| `aquarium/cooling/status/ota_upload_url` | publish | Active OTA upload URL or `unavailable` |
| `aquarium/cooling/status/remote_config_last_result` | publish | Last remote-config apply result |
| `aquarium/cooling/status/remote_config_last_key` | publish | Key name of the last remote-config command |
| `aquarium/cooling/status/remote_config_last_detail` | publish | Last remote-config apply/reject detail |
| `aquarium/cooling/status/availability` | publish | MQTT online/offline availability |
| `aquarium/cooling/set/target_temp_c` | subscribe | Remote target temperature |
| `aquarium/cooling/set/cooling_on_delta_c` | subscribe | Remote upper hysteresis delta relative to target |
| `aquarium/cooling/set/cooling_off_delta_c` | subscribe | Remote lower hysteresis delta relative to target |
| `aquarium/cooling/set/high_cooling_delta_c` | subscribe | Remote `fan-high` delta relative to target |
| `aquarium/cooling/set/fan_low_pwm_percent` | subscribe | Remote fixed PWM for `fan-low` |
| `aquarium/cooling/set/fan_high_pwm_percent` | subscribe | Remote fixed PWM for `fan-high` |
| `aquarium/cooling/set/ota_enable` | subscribe | Open or cancel the temporary OTA maintenance window |

The production firmware shall publish a complete telemetry snapshot at a
60-second default interval. Accepted remote-configuration changes and changes to
`controller_mode`, `fan_pwm_percent`, `fan_fault`, `alarm_code`,
`fault_severity`, `fault_response`, `water_sensor_ok`, `cooling_degraded`, and
`service_required` shall trigger an immediate additional publish without
waiting for the next baseline interval.

#### FHEM MQTT2 Monitoring Integration

The repository includes a FHEM `MQTT2_DEVICE` definition at:

```text
integrations/fhem/aquarium-cooling-mqtt2-device.cfg
```

It maps the documented MQTT telemetry topics to explicit FHEM readings and
shall expose the validated `setList` for the supported controller parameters
plus OTA maintenance-window control. The file uses the field-validated root
topic `aquarium_cooling`; deployments using the committed default root
`aquarium/cooling` must adjust the root topic before importing it into FHEM.

#### FHEM / DBLog Field Profile

For long-running database logging, the documented field profile shall remain
deliberately small and focus on tuning plus basic fault visibility while
throttling high-cadence FHEM event churn.

Recommended permanent DBLog include profile:

```text
water_temp_c:1800,target_temp_c:86400,fan_pwm_percent:300,controller_mode,fan_fault,alarm_code,fault_severity,fault_response,availability
```

The field-validated FHEM event profile shall use:

```text
event-on-change-reading .*
event-min-interval .*:1800
```

The following categories shall not be part of the permanent DBLog include by
default:

- detailed RPM and plausibility diagnostics
- OTA detail readings
- remote-config diagnostic details
- any air-sensor-related telemetry

For the 120-liter production aquarium, the DBLog suffixes keep long-running
water trend and fan-command history compact. Fault, mode, and availability
readings stay in the include list so their latest state remains visible through
FHEM even when regular event output is globally throttled.

Detailed fan and plausibility readings may be enabled temporarily for targeted
diagnostic campaigns and removed again afterward.

#### OTA Update Interface

| Element | Direction | Purpose |
|---|---|---|
| OTA enable command | operator -> ESP32 | Open a short maintenance window for local firmware upload |
| OTA upload endpoint | host -> ESP32 | Accept one compiled firmware `.bin` image; no ZIP, manifest, password, or token |
| OTA result status | publish/log | Report update progress, success, or failure |

### 6.2 Internal Interfaces

| Producer | Consumer | Interface |
|---|---|---|
| `sensor_manager` | `control_engine` | Water temperature samples |
| `config` | `control_engine` | Validated target and staged-control settings |
| `control_engine` | `fan_driver` | Commanded PWM percentage |
| `fan_driver` | `rpm_monitor` | Active PWM state for settling logic |
| `rpm_monitor` | `fault_monitor` | Measured RPM |
| `fan_curve` | `fault_monitor` | Expected RPM interpolation lookup |
| `fault_monitor` | `fault_policy` | Fan plausibility state and latched fan fault |
| `sensor_manager` | `oled_status_display` | Rounded water-temperature source for the local display |
| `fault_policy` | `oled_status_display` | Active alarm class for local fault rendering |
| `fault_policy` | `telemetry` | Alarm code, severity, response, and service state |

### 6.3 Data Models / Schemas

#### Fan Curve Point

| Field | Type | Description |
|---|---|---|
| `pwm_percent` | `uint8_t` | PWM command in percent |
| `rpm` | `uint16_t` | Measured RPM |

#### Persisted Configuration

| Key | Type | Description |
|---|---|---|
| `target_c` | float | Desired water temperature |
| `target_set` | bool | Marks whether a custom target temperature is stored |
| `cooling_on_delta_c` | float | Upper hysteresis delta relative to target |
| `cooling_off_delta_c` | float | Lower hysteresis delta relative to target |
| `high_cooling_delta_c` | float | Delta relative to target that enters `fan-high` |
| `fan_low_pwm_percent` | uint8 | Fixed PWM used for `fan-low` |
| `fan_high_pwm_percent` | uint8 | Fixed PWM used for `fan-high` |

#### Remote Configuration Validation Model

- The controller shall accept individual MQTT set topics for
  `target_temp_c`, `cooling_on_delta_c`, `cooling_off_delta_c`,
  `high_cooling_delta_c`, `fan_low_pwm_percent`, and
  `fan_high_pwm_percent`.
- Each incoming update shall be validated against the complete resulting
  configuration profile before it is applied or persisted.
- Valid values shall be applied immediately to the runtime controller and then
  persisted in Preferences/NVS.
- Invalid or inconsistent updates shall be rejected without overwriting the
  last valid persisted settings.

Validation ranges for the normal staged control surface:

| Field | Allowed Range / Rule |
|---|---|
| `target_temp_c` | Existing controller target range |
| `cooling_on_delta_c` | `+0.1 .. +3.0 C` |
| `cooling_off_delta_c` | `-3.0 .. -0.1 C` |
| `high_cooling_delta_c` | `> cooling_on_delta_c`, at least `cooling_on_delta_c + 0.1 C` |
| `fan_low_pwm_percent` | `15 .. 60` |
| `fan_high_pwm_percent` | `20 .. 100` |

Consistency rules:

- `cooling_off_delta_c < 0`
- `cooling_on_delta_c > 0`
- `high_cooling_delta_c > cooling_on_delta_c`
- `fan_high_pwm_percent > fan_low_pwm_percent`

#### Diagnostics Payload

| Field | Type | Description |
|---|---|---|
| `expected_rpm` | integer | Interpolated expected RPM |
| `measured_rpm` | integer | Measured fan RPM |
| `rpm_error_absolute` | integer | Absolute RPM deviation |
| `rpm_error_percent` | float | Relative deviation |
| `fan_plausible` | bool | Current plausibility result |
| `fan_fault` | bool | Latched fault state |
| `alarm_code` | string | Current summarized fault code |
| `fault_severity` | string | `none`, `warning`, or `critical` |
| `fault_response` | string | Current local fault response |
| `cooling_degraded` | bool | Whether local cooling effectiveness is degraded |
| `service_required` | bool | Whether operator/service action is required |

#### Firmware Release Metadata

| Field | Type | Description |
|---|---|---|
| `firmware_version` | SemVer string | Production firmware version in `MAJOR.MINOR.PATCH` form, with optional SemVer-compliant pre-release or build metadata |
| `release_date` | ISO date | Date assigned to the released firmware version in `CHANGELOG.md` |
| `changelog_section` | Markdown section | Keep a Changelog release section containing grouped notable changes for the version |
| `release_state` | enum/string | `unreleased`, `pre-release`, or `released` |

#### OLED Display State Model

| Field | Type | Description |
|---|---|---|
| `display_available` | bool | Whether a compatible OLED was detected and initialized |
| `display_mode` | enum/string | `boot`, `temperature`, `fault`, or `disabled` |
| `display_text_primary` | string | Main rendered content such as `BOOT`, `23.4`, or `!` |
| `display_text_secondary` | string | Optional fault text such as `WATER`, `FAN`, or `BOTH` |

### 6.4 Commands / Opcodes

The system does not define a custom binary command protocol. The current local
controller exposes a small text-based USB serial service interface for bench
operation and diagnostics:

| Command | Purpose |
|---|---|
| `status` | Print an immediate diagnostics block |
| `target <c>` | Set and persist a custom water target temperature |
| `default` | Clear persisted target and return to the default `23.0 C` |
| `control` | Print the current hysteresis and staged-PWM control defaults |
| `faults` | Print the current local fault-policy defaults |
| `network` | Print Wi-Fi/MQTT configuration and connection status |
| `publish` | Publish telemetry immediately when MQTT is connected |
| `help` | Print the supported command list |

Future production command inputs may additionally be represented by validated
MQTT set topics and an explicitly enabled OTA firmware upload maintenance
window over Wi-Fi. Characterization mode remains fully automatic with no
runtime command input. The existing diagnostics output includes OLED detection
and current display state for Phase 4 bring-up and field support.

## 7. Operational Procedures

### Deployment / Flashing

1. Assemble the ESP32, fan power path, tach pull-up, PWM interface, 1-Wire bus,
   and 3-pin metal circular water-sensor connector.
2. Verify common ground between the fan supply and ESP32.
3. Flash the characterization sketch for first article testing.
4. Record the measured fan curve and minimum stable PWM data.
5. Integrate measured values into production firmware.
6. For the OLED feature workstream, development and OTA test builds used
   version numbers starting at `0.2.1` before the release candidate was
   promoted to `0.3.0`.
7. Assign or update the production firmware SemVer version and update
   `CHANGELOG.md` before building a release candidate.
8. Build production firmware with:

   ```powershell
   powershell -ExecutionPolicy Bypass -File .\tools\build.ps1
   ```

9. For normal OTA delivery without USB, flash production firmware with:

   ```powershell
   powershell -ExecutionPolicy Bypass -File .\tools\ota-upload.ps1
   ```

10. Use `tools/mqtt-client.ps1` for normal broker-side MQTT inspection or
   control, and reserve direct `mosquitto_pub.exe` / `mosquitto_sub.exe`
   troubleshooting for raw client debugging only.
11. The optional OLED did not need to be physically connected before the first
    `0.2.1+` development flashes, provided the display path was implemented as
    optional and fail-open.
12. Treat `.arduino-build/esp32_esp32_esp32/` as the canonical working build
    path, including board-scoped `logs/` and `output/`.
13. Treat `bin/` as the canonical release-artifact directory for versioned
    firmware BIN files.
14. Treat `build/` as a bench-side ad-hoc output directory for local serial
    captures and similar temporary artifacts. The sketch-local
    `firmware/controller/build/` directory is an ignored Arduino tooling
    artifact and may be deleted at any time.

### Provisioning / Configuration

1. With controller power disconnected, wire the water-sensor connector using
   the insert-marked contacts: pin 1 = 3.3 V/VCC, pin 2 = GND, and pin 3 =
   DATA/GPIO33. Keep the 3.3 kOhm DATA pull-up on the controller side.
2. Verify continuity from the controller-side connector contacts through the
   mating sensor-side contacts before connecting power.
3. Assign the DS18B20 water-sensor role by ROM ID.
4. Store the default target temperature in NVS.
5. Validate persisted values at boot.
6. In production mode, connect to Wi-Fi and MQTT only after local control is
   active.
7. Configure the OTA upload policy before enabling OTA in production. The
   initial OTA design shall not require a password or token.
8. If an OLED is connected, verify its `I2C` wiring on GPIO32/GPIO27 and
   confirm the normal temperature view only after the core controller bring-up
   remains stable.

### Normal Operation

1. Sample water temperature at the configured interval.
2. Compare water temperature against the configured hysteresis thresholds
   relative to target.
3. Enter `fan-low`, `fan-high`, or `fan-off` based on those thresholds while
   holding the current state inside the hysteresis band and across the
   documented stage transitions.
4. Apply the resulting fixed PWM command for the active state.
5. Allow settling time after PWM changes before plausibility evaluation.
6. Measure fan RPM and evaluate plausibility where valid.
7. Publish a full telemetry snapshot every 60 seconds by default and accept
   validated remote settings when connected.
8. Publish an immediate extra telemetry snapshot when a documented
   controller-mode, PWM, or fault-policy event state changes.
9. If a compatible OLED is available, show `BOOT` during startup, the large
   water-temperature value during normal operation, or `!` plus a fault label
   during active alarms.
10. If no compatible OLED is present, keep the display path disabled with no
    effect on normal operation.
11. Keep OTA upload disabled unless an operator explicitly opens the maintenance
   window while local control remains active.

### Maintenance Procedures

1. Re-run fan characterization if the fan model changes.
2. Re-run characterization if the installed airflow path changes materially.
3. Inspect diagnostics for drift between expected and measured RPM.
4. Verify sensor ROM-ID assignment after replacing a DS18B20 sensor.
5. After connector or sensor-cable work, perform an unpowered continuity test
   of pins 1 through 3 before reconnecting the sensor and powering the system.
6. Trigger and verify OTA uploads only when the system is in a stable operating
   condition and the local network client is trusted.
7. Before publishing a firmware release, verify that the firmware version is a
   valid SemVer value and that `CHANGELOG.md` contains a corresponding Keep a
   Changelog release entry.
8. Retain basic real OLED hardware-verification evidence when publishing
   `0.3.0` or later display-related releases.

### Recovery Procedures

1. On invalid persisted configuration, reset affected keys to defaults and log
   the recovery.
2. On water-sensor failure, enter `water-fallback` at `40%` PWM and raise a
   critical alarm.
3. On network failure, continue local control with the last valid persisted
   settings.
4. On confirmed fan fault, keep the locally computed PWM command, raise a
   critical `fan-fault`, and require service. Hardware tests with missing tach
   feedback and a deliberately slowed fan verified this response; no automatic
   fan-fault boost is currently applied.
5. On OTA upload or validation failure, remain on the currently working
   firmware and report the failed update state.
6. If no compatible OLED is detected or the OLED later fails, disable the
   display path and continue normal controller operation without raising a
   controller fault solely for the missing display.

## 8. Verification & Validation

### 8.1 Phase 1 Verification

| Test ID | Feature | Procedure | Success Criteria |
|---|---|---|---|
| TC-P1-01 | Standalone characterization | Flash `firmware/fan-test/fan-test.ino` and boot with connected fan | Sketch starts without requiring serial input |
| TC-P1-02 | Start PWM detection | Observe automatic search from stop to running state | Safe start PWM is reported |
| TC-P1-03 | Increasing curve | Run full upward sweep from detected start PWM | PWM/RPM points are printed up to 100% |
| TC-P1-04 | Decreasing curve | Run full downward sweep from 100% to 0% | PWM/RPM points are printed down to 0% |
| TC-P1-05 | Hold PWM detection | Observe running fan while PWM is decreased stepwise | Minimum hold PWM is reported |
| TC-P1-06 | Reusable output | Inspect serial summary and code block | Readable table and C-array initializer are printed |

### 8.2 Phase 2 Verification

| Test ID | Feature | Procedure | Success Criteria |
|---|---|---|---|
| TC-P2-01 | DS18B20 role assignment | Boot with the water sensor connected and its known ROM ID | Water role maps to the correct sensor |
| TC-P2-02 | Water-threshold control | Simulate water temperature below, near, and above target | Fan state switches at the documented hysteresis thresholds |
| TC-P2-03 | Hysteresis hold behavior | Move water temperature within the band after entering `fan-off`, `fan-low`, and `fan-high` | Current state is held until the documented transition threshold is crossed |
| TC-P2-04 | Fixed cooling stages | Drive water temperature above the upper threshold and then above the high-stage threshold | Commanded PWM equals the documented `fan-low` and `fan-high` stage values |
| TC-P2-05 | NVS persistence | Change target temperature and staged-control settings, reboot device | Values survive reboot and reload correctly |
| TC-P2-06 | RPM measurement | Drive fan at stable PWM and compare with tach observations | RPM measurement is plausible and repeatable |
| TC-P2-07 | Fault debounce | Inject repeated RPM mismatches above stable PWM | Fault latches only after configured consecutive mismatches |
| TC-P2-08 | Water sensor failure | Disconnect or invalidate water sensor input | Controller enters defined fallback behavior and raises fault |
| TC-P2-09 | Recovery debounce | Restore valid RPM after induced mismatch series | Recovery occurs only after configured consecutive matches |
| TC-P2-10 | Critical/runtime memory discipline | Inspect critical control path under normal operation and review implementation for avoidable heap use | No unnecessary dynamic allocation is present in critical runtime paths |
| TC-P2-11 | Control/communication separation | Review module boundaries and disable network stack during runtime tests | Local control remains operational with communication logic absent or inactive |
| TC-P2-12 | Boot sequencing | Boot with valid persisted config and delayed/unavailable network | Local control becomes valid before network initialization is required |
| TC-P2-13 | OTA non-blocking startup | Boot with OTA support compiled in and no active OTA maintenance window | Local cooling starts before any OTA upload service is available |
| TC-P2-14 | Detachable water-sensor connector | With power off, verify continuity across both connector halves for pins 1 through 3, reconnect the sensor, boot, and inspect the recognized ROM ID and temperature | Pin 1 carries 3.3 V/VCC, pin 2 is GND, pin 3 connects DATA to GPIO33, no pins are crossed, and the configured DS18B20 is recognized after reconnection |

### 8.3 Phase 4 Verification

| Test ID | Feature | Procedure | Success Criteria |
|---|---|---|---|
| TC-P4-01 | No OLED connected | Boot a `0.2.1+` display-capable firmware build with no OLED attached | Controller boots normally and local cooling remains fully operational |
| TC-P4-02 | No-display network/service behavior | Run MQTT, OTA enablement, and fault handling with no OLED attached | MQTT, fault handling, and OTA behavior remain unchanged by the missing display |
| TC-P4-03 | Display diagnostics without hardware | Inspect serial diagnostics on a no-display boot when display support is compiled in | Diagnostics make it clear that no compatible OLED was detected, if the diagnostics feature is implemented |
| TC-P4-04 | Boot view on real OLED | Connect the OLED and boot the controller | Display shows `BOOT` before the first stable runtime display state |
| TC-P4-05 | Normal temperature rendering | Run with a healthy water sensor and connected OLED | Display shows only the large one-decimal water-temperature value |
| TC-P4-06 | Water fault rendering | Induce a water-sensor fault with connected OLED | Display shows a large `!` plus `WATER` |
| TC-P4-07 | Fan fault rendering | Induce a fan fault with connected OLED | Display shows a large `!` plus `FAN` |
| TC-P4-08 | Combined fault rendering and v1 scope limit | Induce a combined fault and inspect steady-state display behavior | Display shows `!` plus `BOTH` and never rotates pages or shows RPM/multi-value content |

### 8.4 Acceptance Tests

| Test ID | Scenario | Procedure | Success Criteria |
|---|---|---|---|
| AT-01 | Autonomous cooling without network | Run production firmware with Wi-Fi and MQTT unavailable | Cooling control remains active locally |
| AT-02 | Persisted configuration resilience | Store target temperature, reboot, then boot without network | Target remains active and cooling still works |
| AT-03 | MQTT observability | Connect broker and inspect published topics | Required state, diagnostic, and status topics for the staged control surface are published, including active controller parameters, one-decimal temperature values, OTA endpoint discovery, and remote-config status feedback |
| AT-04 | Remote configuration safety | Publish valid and invalid set commands for each supported parameter | Valid values apply immediately, persist, and remain consistent; invalid values are rejected without overwriting the last valid persisted settings |
| AT-05 | FHEM MQTT2 integration | Import the FHEM definition against the configured broker/root topic | FHEM receives the expected telemetry readings and can issue only the documented validated set commands for the controller parameters and OTA control |
| AT-06 | Installed staged water-only control | Run controller in actual aquarium installation through light and dark phases | Water remains inside the accepted operating band with materially reduced fan runtime and no air-driven overcooling |
| AT-07 | OTA success path | Run `tools/ota-upload.ps1` against a newer valid `.bin` firmware image from the local network | Firmware uploads, validates, reboots, returns to MQTT `availability=online`, and reports the new `firmware_version` |
| AT-08 | OTA failure rollback | Interrupt upload or upload an invalid `.bin` image during update test | Device preserves current working firmware and reports failure |
| AT-09 | DBLog field profile | Export long-running FHEM/DBLog data with the documented include list, `event-on-change-reading .*`, and `event-min-interval .*:1800` | Core water, fan-state, fault, and availability analysis remains possible without logging high-volume diagnostic detail topics |
| AT-10 | Release versioning and changelog | Inspect a release candidate before publication | Firmware version follows SemVer 2.0.0 and `CHANGELOG.md` follows Keep a Changelog with a matching release entry |
| AT-11 | MQTT hybrid cadence | Run production firmware with stable temperatures, then trigger a mode change, a fault-state change, and a valid remote setting update | A full telemetry snapshot is published every 60 seconds during steady state, while the documented controller/fault events and accepted remote settings trigger immediate additional publishes |
| AT-12 | OTA upgrade without real OLED hardware | OTA-update the installed `0.2.0` controller to a newer `0.2.1+` OLED-capable development build while no OLED is attached | Update succeeds and the controller remains fully operational without the display |
| AT-13 | Final OLED feature release readiness | Review the completed OLED feature candidate after real display verification | Final release uses version `0.3.0`, has a matching changelog entry, and includes completed real-OLED verification evidence |

### 8.5 Traceability Matrix

Status interpretation in this matrix:

- `Covered`: completed and verified in the current project phase
- `Bench-verified`: implemented and verified on the current bench setup
- `Implemented`: present in firmware but not yet fully validated in the final installation context
- `Planned`: specified but not yet implemented or verified

| Requirement | Priority | Test Case(s) | Status |
|---|---|---|---|
| FR-1.1 | Must | TC-P1-01 | Covered |
| FR-1.2 | Must | TC-P1-02 | Covered |
| FR-1.3 | Must | TC-P1-03 | Covered |
| FR-1.4 | Must | TC-P1-04 | Covered |
| FR-1.5 | Must | TC-P1-05 | Covered |
| FR-1.6 | Must | TC-P1-06 | Covered |
| FR-2.1 | Must | TC-P2-01 | Bench-verified |
| FR-2.2 | Must | TC-P2-02 | Planned |
| FR-2.3 | Must | TC-P2-02, TC-P2-04 | Planned |
| FR-2.4 | Must | TC-P2-03, TC-P2-04 | Planned |
| FR-2.5 | Must | TC-P2-03 | Planned |
| FR-2.6 | Should | TC-P2-04 | Planned |
| FR-2.7 | Must | TC-P2-02, TC-P2-06 | Bench-verified |
| FR-2.8 | Must | TC-P2-06 | Bench-verified |
| FR-2.9 | Must | TC-P2-05, AT-02 | Bench-verified |
| FR-2.10 | Must | TC-P2-05 | Bench-verified |
| FR-2.11 | Must | AT-01, AT-02 | Bench-verified |
| FR-2.12 | Must | TC-P2-14 | Planned |
| FR-3.1 | Must | TC-P2-07, AT-06 | Bench-verified |
| FR-3.2 | Must | TC-P2-07, AT-06 | Bench-verified |
| FR-3.3 | Must | TC-P2-07 | Bench-verified |
| FR-3.4 | Must | TC-P2-07, AT-03 | Bench-verified |
| FR-3.5 | Must | TC-P2-08 | Implemented |
| FR-3.6 | Should | TC-P2-09 | Implemented |
| FR-4.1 | Must | AT-03 | Bench-verified |
| FR-4.2 | Must | AT-04 | Bench-verified |
| FR-4.3 | Should | AT-04 | Bench-verified |
| FR-4.4 | Must | AT-07, AT-08 | Bench-verified |
| FR-4.5 | Must | TC-P2-12, TC-P2-13, AT-07 | Bench-verified |
| FR-4.6 | Must | AT-07, AT-08 | Bench-verified |
| FR-4.7 | Must | AT-08 | Implemented |
| FR-4.8 | Should | AT-07, AT-08 | Implemented |
| FR-4.9 | Should | AT-05 | Bench-verified |
| FR-4.10 | Must | AT-11 | Bench-verified |
| FR-4.11 | Must | AT-11 | Bench-verified |
| FR-5.1 | Must | TC-P4-01, TC-P4-04 | Planned |
| FR-5.2 | Must | TC-P4-05 | Planned |
| FR-5.3 | Must | TC-P4-04 | Planned |
| FR-5.4 | Must | TC-P4-06, TC-P4-07, TC-P4-08 | Planned |
| FR-5.5 | Must | TC-P4-06, TC-P4-07, TC-P4-08 | Planned |
| FR-5.6 | Must | TC-P4-08 | Planned |
| FR-5.7 | Must | TC-P4-01, TC-P4-02 | Planned |
| FR-5.8 | Should | TC-P4-05 | Planned |
| FR-5.9 | Must | TC-P4-01, TC-P4-02 | Planned |
| FR-5.10 | Should | TC-P4-03 | Planned |
| NFR-1.1 | Must | AT-01 | Bench-verified |
| NFR-1.2 | Must | TC-P2-02, TC-P2-03, AT-06 | Planned |
| NFR-1.3 | Must | TC-P2-05, AT-02 | Bench-verified |
| NFR-1.4 | Must | TC-P2-02, TC-P2-07 | Bench-verified |
| NFR-1.5 | Must | TC-P2-10 | Implemented |
| NFR-1.6 | Should | TC-P2-11 | Implemented |
| NFR-1.7 | Must | TC-P2-07, TC-P2-08, AT-03 | Bench-verified |
| NFR-1.8 | Should | TC-P2-12, AT-01, AT-02 | Implemented |
| NFR-1.9 | Must | TC-P1-01 | Covered |
| NFR-1.10 | Must | TC-P2-13, AT-01 | Bench-verified |
| NFR-1.11 | Must | AT-07, AT-08 | Bench-verified |
| NFR-1.12 | Must | AT-10 | Implemented |
| NFR-1.12a | Must | AT-12, AT-13 | Planned |
| NFR-1.13 | Must | AT-10 | Implemented |
| NFR-1.14 | Should | AT-09, AT-11 | Bench-verified |

## 9. Troubleshooting Guide

| Symptom | Likely Cause | Diagnostic Steps | Corrective Action |
|---|---|---|---|
| Fan does not start at low PWM | Start threshold too low or PWM interface incompatible | Run characterization and inspect start PWM result | Increase start-boost or validate PWM electrical stage |
| RPM reads zero while fan spins | Tach wiring or pull-up problem | Check GPIO26 signal, pull-up, and common ground | Correct wiring and confirm pulse measurement |
| Water temperature seems implausible | Wrong DS18B20 identified as the water sensor | Print detected ROM IDs and compare to the configured water-sensor mapping | Reassign and persist the correct water-sensor ROM ID |
| Water temperature is unavailable after reconnecting the sensor | Circular connector is unplugged, a contact is loose, or pin numbering was mirrored during wiring | Disconnect power and check continuity against the insert-marked contacts: pin 1 = 3.3 V/VCC, pin 2 = GND, pin 3 = DATA/GPIO33 | Correct both connector halves to the fixed pinout, reconnect while unpowered, and verify the configured sensor ROM after boot |
| Water remains too warm during hot periods | Low stage is too weak or high stage enters too late | Compare water trend, controller mode, and configured deltas through a full light phase | Increase `fan_low_pwm_percent`, `fan_high_pwm_percent`, or reduce `high_cooling_delta_c` through validated configuration |
| False fan faults near low PWM | Unstable tach region below stable operating range | Compare measured RPM to stable hold PWM region | Exclude low-PWM region or widen tolerance there |
| Cooling stops after water sensor issue | Fallback behavior not configured or not applied correctly | Inspect fault logs and safe fallback branch | Implement and verify defined safe fallback PWM |
| OLED stays dark | OLED is not connected, wired incorrectly, at a different `I2C` address, or intentionally disabled after failed detection | Inspect serial diagnostics, verify `I2C` wiring and power, and confirm that the controller still runs normally without the display | Correct wiring or attach a compatible OLED; no controller-side recovery is required if the display remains optional |
| OLED always shows `!` | A real water/fan alarm is active or the display is repeatedly re-entering the fault view after a valid alarm | Inspect controller fault diagnostics, `alarm_code`, and sensor/fan health | Resolve the underlying water or fan fault; missing OLED hardware itself is not a controller alarm |
| MQTT updates seem ignored | Network unavailable or payload invalid | Check broker connection and validation logs | Restore connectivity or send valid payload |
| FHEM readings do not update | FHEM IODev or topic root does not match the broker traffic | Compare the serial `network` root topic with the FHEM `readingList`; inspect broker traffic for `<root>/status/availability` | Correct the IODev, subscription, credentials, or root topic |
| OTA upload page is not reachable | OTA maintenance window is not enabled, Wi-Fi is unavailable, or the window timed out | Check Wi-Fi state, OTA state, serial/MQTT diagnostics, and the published `ota_upload_url` | Enable OTA maintenance mode again or restore Wi-Fi connectivity |
| OTA update fails validation | Corrupt image, wrong firmware image, unsupported image, or image too large for the OTA slot | Inspect OTA result code and firmware release identity diagnostics | Rebuild and upload a valid firmware `.bin` image |
| Duplicate firmware binaries appear under `firmware/controller/build/` | Arduino tooling created a sketch-local build artifact directory in addition to the repository-standard artifact folders | Inspect `build.options.json` under `firmware/controller/build/` and compare it with the documented CLI build paths | Keep `.arduino-build/` as the working build path, keep root `build/` for exported artifacts and logs, and delete the sketch-local `build/` tree when it is no longer needed |

## 10. Appendix

### A. Current Characterization Parameters

| Constant | Value |
|---|---:|
| PWM frequency | 25000 Hz |
| PWM resolution | 8 bit |
| Tach pulses per revolution | 2 |
| Start search step | 1 % |
| Curve step | 5 % |
| Settle time | 3000 ms |
| Samples per point | 4 |
| RPM start threshold | 150 RPM |
| Stable samples required | 3 |
| Maximum stored curve points | 32 |

### B. Proposed Simplified Water-Only Control Defaults

| Constant | Value |
|---|---:|
| Water target delta to enter cooling | +0.5 C |
| Water target delta to leave cooling | -0.5 C |
| Water target delta to enter `fan-high` | +1.0 C |
| Fixed `fan-low` cooling PWM | 45 % |
| Fixed `fan-high` cooling PWM | 60 % |

### C. Default Naming

| Item | Value |
|---|---|
| Repository name | `aquarium-cooling-controller` |
| Device name | `aquarium-cooling-controller` |
| Hostname | `aq-cooling` |
| MQTT root topic | `aquarium/cooling` |
| FHEM integration | `integrations/fhem/aquarium-cooling-mqtt2-device.cfg` |
| Changelog file | `CHANGELOG.md` |

Local verified MQTT root topic override on `2026-04-16`: `aquarium_cooling`.

### D. Versioning and Changelog Policy

- Production firmware versions shall follow Semantic Versioning 2.0.0:
  `MAJOR.MINOR.PATCH`.
- During initial development, `0.y.z` versions may be used to indicate that
  compatibility can still change before a stable `1.0.0` release.
- Patch versions shall be used for backward-compatible bug fixes.
- Minor versions shall be used for backward-compatible feature additions,
  deprecations, or substantial compatible improvements.
- Major versions shall be used for backward-incompatible changes to the
  documented project surface, including serial commands, MQTT topics,
  persisted configuration semantics, OTA compatibility, or documented control
  behavior.
- Pre-release and build metadata may be used only when the resulting version
  string remains SemVer-compliant.
- `CHANGELOG.md` shall follow Keep a Changelog and keep an `Unreleased`
  section above released versions.
- Changelog entries shall be grouped under the standard headings `Added`,
  `Changed`, `Deprecated`, `Removed`, `Fixed`, and `Security` when those
  categories apply.
- Each published firmware version shall have a corresponding changelog release
  section with the release date.
- The OLED feature workstream advanced through `0.2.1+` OTA-testable
  development builds above the `0.2.0` baseline before promotion to release
  `0.3.0`.

### E. Build Artifact Directory Policy

- `powershell -ExecutionPolicy Bypass -File .\tools\build.ps1` is the canonical
  repository build entrypoint for firmware compilation and artifact export.
- `.arduino-build/esp32_esp32_esp32/` is the canonical working build path used
  by the repository build script, including board-scoped `logs/` and `output/`
  directories.
- `powershell -ExecutionPolicy Bypass -File .\tools\mqtt-client.ps1` is the
  canonical repository entrypoint for normal MQTT reads and writes.
- `powershell -ExecutionPolicy Bypass -File .\tools\ota-upload.ps1` is the
  canonical repository entrypoint for OTA flashing when no USB-connected ESP is
  in use.
- `bin/` is the canonical location for versioned exported firmware binaries
  created by `tools/build.ps1`.
- `build/` is reserved for local serial or bench-capture logs and other ad-hoc
  temporary outputs.
- `firmware/controller/build/` is a sketch-local Arduino tooling artifact
  directory that may contain duplicated binaries and `build.options.json`.
- The sketch-local `firmware/controller/build/` tree is ignored by Git and may
  be deleted whenever it is not actively needed by local tooling.

### F. Wiring Summary

| Signal | Mapping |
|---|---|
| Fan pin 1 | Black -> GND |
| Fan pin 2 | Red -> +12 V fan supply |
| Fan pin 3 | Yellow -> TACH -> ESP32 GPIO26, with 3.3 kOhm pull-up to 3.3 V |
| Fan pin 4 | Blue -> PWM -> ESP32 GPIO25 |
| DS18B20 connector pin 1 | 3.3 V/VCC -> sensor red wire (`rot`) |
| DS18B20 connector pin 2 | Common GND -> sensor yellow wire (`gelb`) |
| DS18B20 connector pin 3 | ESP32 GPIO33 DATA -> sensor green wire (`gruen`), with 3.3 kOhm pull-up to 3.3 V on the controller side |
| OLED SDA (optional) | ESP32 GPIO32 -> OLED SDA |
| OLED SCL (optional) | ESP32 GPIO27 -> OLED SCL |

### G. Verified Fan Characterization Result

Latest verified bench result on `2026-04-12` with `Noctua NF-S12A PWM`:

| Metric | Value |
|---|---:|
| Start PWM from standstill | 12 % |
| Minimum hold PWM while spinning | 10 % |
| RPM at 0 % PWM | 0 |
| RPM at 5 % PWM | 0 |
| RPM at 100 % PWM | 1252 |

Reference artifacts:

- `docs/result fan test/measurement-summary-2026-04-12.md`
- `docs/result fan test/live-run.txt`
- `docs/result fan test/live-run-part2.txt`

Verified upward curve:

```cpp
FanCurvePoint curve[] = {
  {12, 187},
  {17, 277},
  {22, 352},
  {27, 435},
  {32, 517},
  {37, 570},
  {42, 637},
  {47, 697},
  {52, 765},
  {57, 832},
  {62, 885},
  {67, 930},
  {72, 997},
  {77, 1050},
  {82, 1102},
  {87, 1147},
  {92, 1185},
  {97, 1230},
  {100, 1252},
};
```

### H. Open Points Requiring Finalization

- Final plausibility tolerance percentage after measured tuning
- Final hardware implementation of PWM electrical compatibility
- Whether installed airflow requires a separate in-situ fan curve
- Exact OTA upload window duration and final service-policy details
- Rework the 3-pin water-sensor circular-connector documentation after
  checking the real plug and socket; add a correct, clearly oriented photo
  showing contact numbers, plug/socket side, and the final verified wiring

### I. Draft Schematic Sketch

- Mermaid source: `docs/design/schematic-sketch.mmd`
- Usage: paste the Mermaid source into draw.io via `Arrange -> Insert ->
  Advanced -> Mermaid`
- Scope: block-level sketch for architecture and wiring orientation, not yet a
  final electrical schematic

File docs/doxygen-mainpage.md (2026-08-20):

# Aquarium Cooling Controller API

This generated documentation covers the ESP32 firmware interfaces for staged
water-only aquarium cooling control, fan PWM output, fan RPM monitoring,
OneWire temperature sampling, MQTT telemetry, serial diagnostics, OTA update
support, and fault policy decisions.

Use the project README for setup, wiring, build, and operating instructions.
This Doxygen site focuses on source-level API documentation.

## Firmware Areas

- Control engine: water-only staged cooling, runtime validation, and PWM
  command calculation.
- Fan curve: measured PWM-to-RPM mapping and plausibility helpers.
- Fan driver: ESP32 LEDC PWM output with low-speed start boost.
- RPM monitor: interrupt-driven tachometer pulse counting.
- Fault monitor and policy: fan plausibility, alarm state, severity, and response.
- Sensor manager: OneWire discovery and DS18B20 water-temperature sampling.
- OLED status display: optional local boot, temperature, and fault rendering.
- MQTT telemetry: network status, controller-state publishing, and validated
  remote configuration for control parameters.
- Controller sketch: Arduino setup/loop orchestration, serial diagnostics, target
  persistence, OTA upload plumbing, OLED integration, and module wiring.

## Circuit Summary

- ESP32 board running the Arduino core.
- DS18B20 water sensor on the shared OneWire bus.
- Optional `0.91"` monochrome `128x32` `I2C` OLED on GPIO32 / GPIO27.
- Four-wire PWM fan with separate PWM command and tachometer feedback.
- MQTT telemetry is optional; local cooling continues without Wi-Fi or broker access.
- MQTT can update target temperature, hysteresis deltas, and fixed low/high PWM
  stages, with persisted validation on the controller.

## Arduino Runtime

The firmware follows the standard Arduino lifecycle:

- `setup()` configures serial diagnostics, preferences, sensors, fan PWM, RPM
  sampling, and telemetry.
- `loop()` remains non-blocking and repeatedly advances sensor sampling, control
  calculation, PWM output, RPM measurement, fault evaluation, diagnostics, and
  telemetry publishing.

## Documentation Policy

This site is generated with `WARN_AS_ERROR = YES`, so Doxygen warnings fail the
GitHub Pages build. New firmware modules should include `@file` documentation,
explicit API comments, and Arduino-specific notes for pins, timing, units, and
runtime assumptions.

## Generated Output

The GitHub Pages workflow builds this site from `Doxyfile` and publishes the
HTML output from `docs/doxygen/html`.

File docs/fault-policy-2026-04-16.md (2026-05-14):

# Fault Policy - 2026-04-16

> Historischer Hinweis:
> Dieses Dokument beschreibt den Fault-Policy-Stand vom `2026-04-16`.
> Die aktuelle Firmware nutzt inzwischen die wassergefuehrte Staged-Control
> Architektur ohne aktiven Luftsensorpfad. Luftsensor-spezifische Faults in
> diesem Dokument sind deshalb als frueherer Entwicklungsstand zu lesen, nicht
> als aktueller Sollzustand.

## Ziel

Die lokale Firmware soll Fehler eindeutig klassifizieren, ohne die autonome
Kuehlung von Netzwerkdiensten abhaengig zu machen. Die Policy trennt deshalb
zwischen:

- Fehlererkennung
- Alarmcode
- Schweregrad
- lokaler Reaktion
- Service-/Diagnosehinweis

## Implementierter Stand

Das Modul `fault_policy` bewertet den aktuellen `ControlSnapshot` zusammen mit
dem `FaultMonitorSnapshot`.

Ausgegeben werden:

- `Alarm code`
- `Fault severity`
- `Fault response`
- `Cooling degraded`
- `Service required`
- `Water sensor ok`
- `Air sensor ok`
- `Fan ok`

## Aktuelle Fehlerreaktionen

| Fehler | Alarmcode | Severity | Lokale Reaktion |
|---|---|---|---|
| Kein Fehler | `none` | `none` | `normal-control` |
| Wassersensor ungueltig | `water-sensor-fault` | `critical` | `water-fallback` mit `40%` PWM |
| Luftsensor ungueltig | `air-sensor-fault` | `warning` | `disable-air-assist`, Wasserregelung laeuft weiter |
| Fan-Plausibilitaetsfehler | `fan-fault` | `critical` | `report-fan-fault`, PWM-Befehl bleibt lokal berechnet |
| Wassersensor + Fanfehler | `water-sensor+fan-fault` | `critical` | `water-fallback+report-fan-fault` |
| Luftsensor + Fanfehler | `air-sensor+fan-fault` | `critical` | `report-fan-fault` |
| Mehrfachfehler | `multiple-faults` | `critical` | abhaengig von enthaltenem Wassersensor-/Fanfehler |

## Bewusste Entscheidung fuer Fanfehler

Ein bestaetigter Fan-Plausibilitaetsfehler wird aktuell nicht mit einem
zusaetzlichen PWM-Override beantwortet. Der Controller meldet den Fehler als
kritisch und setzt `serviceRequired`, laesst den lokal berechneten PWM-Befehl
aber unveraendert.

Grund: Bei einem Tach-/Fanfehler ist nicht sicher, ob ein pauschaler Override
auf `100%` die reale Kuehlung verbessert. Ein blockierter oder elektrisch
defekter Fan wird dadurch nicht repariert; bei reinem Tachproblem waere ein
Override nur lauter. Die Hardwaretests mit fehlendem Tachsignal und bewusst
abgebremstem Fan haben bestaetigt, dass die aktuelle Reaktion den Fehler
zuverlaessig meldet und Recovery sauber entprellt. Ein separater
"fan fault boost" wird deshalb aktuell nicht eingefuehrt.

## Service-Kommando

Das Kommando `faults` gibt die aktuellen Policy-Defaults aus:

- Wassersensor-Fallback-PWM
- Luftsensor-Fehlerreaktion
- Fan-Fehlerreaktion
- Mismatch-Zyklen bis Fan-Fault-Latch
- Match-Zyklen bis Recovery
- Settling-Zeit vor Plausibilitaetsbewertung

## Verifizierte Hardwaretests

Alle folgenden Tests wurden am realen ESP32-Aufbau mit zwei DS18B20-Sensoren
und dem Noctua NF-S12A PWM durchgefuehrt.

| Test | Erwartung | Ergebnis |
|---|---|---|
| Normalbetrieb | `Alarm code: none`, alle Komponenten ok | Bestanden |
| Luftsensor getrennt | `air-sensor-fault`, `warning`, `disable-air-assist`, Wasserregelung laeuft weiter | Bestanden |
| Luftsensor wieder verbunden | Rueckkehr auf `none` | Bestanden |
| Wassersensor getrennt | `water-sensor-fault`, `critical`, `water-fallback`, `Final target PWM: 40%` | Bestanden |
| Wassersensor wieder verbunden | Rueckkehr auf `none` | Bestanden |
| Tachsignal getrennt | `fan-fault`, `critical`, `report-fan-fault`, `Fan ok: no` | Bestanden |
| Tachsignal wieder verbunden | Rueckkehr auf `none` nach plausiblen Matches | Bestanden |
| Fan mechanisch abgebremst | RPM ausserhalb Toleranz erzeugt `fan-fault` nach Mismatch-Debounce | Bestanden |
| Fan wieder frei laufend | Rueckkehr auf `none` nach Recovery-Debounce | Bestanden |

Der RPM-Abweichungstest zeigte beispielhaft:

- `Measured RPM: 150`
- `Expected RPM: 661`
- `Tolerance RPM: +/-79`
- `RPM error: -511`
- `Plausible: no`
- anschliessend `Fault latched: yes` und `Alarm code: fan-fault`

Die beobachteten Zustandswechsel im RPM-Abweichungstest waren:

```text
none -> fan-fault -> none -> fan-fault -> none
```

## Offene Punkte

- Kombinierte Mehrfachfehler wie Wassersensor plus Fanfehler sind im
  Policy-Modell enthalten, aber nicht als eigener Hardwaretest blockierend.
- Die Fan-Plausibilitaet sollte im final installierten Luftstrom erneut
  beobachtet werden, falls die reale Montage die Drehzahlkurve merklich
  veraendert.

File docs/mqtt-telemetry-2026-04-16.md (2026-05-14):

# MQTT Telemetry - 2026-04-16

> Historical note:
> This document captures the MQTT telemetry scope as of `2026-04-16`.
> The current controller firmware has since moved to staged water-only control,
> removed the active air-sensor path, and expanded the validated MQTT remote
> configuration surface. Treat this file as an implementation snapshot, not as
> the current source of truth. The current target state is documented in the
> FSD, README, and `integrations/fhem/README.md`.

## Goal

Add Wi-Fi and MQTT observability without making local cooling dependent on
network services. The ESP32 must continue sensor sampling, PWM control, RPM
monitoring, and fault handling if Wi-Fi or the MQTT broker is unavailable.

## Implementation

The controller now contains a dedicated `mqtt_telemetry` module. It handles:

- non-blocking Wi-Fi reconnect attempts
- MQTT reconnect attempts with short socket timeout
- periodic telemetry publishing
- MQTT last-will availability state
- serial status output through the `network` command
- manual publish trigger through the `publish` command

The local control loop remains authoritative. MQTT is publish-only in this
step; remote set commands are deliberately left for a later branch.
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

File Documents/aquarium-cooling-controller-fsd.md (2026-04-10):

# Aquarium Cooling Controller - Functional Specification Document (FSD)

## 1. System Overview

### Purpose

The Aquarium Cooling Controller is an ESP32-based embedded system that reduces
aquarium water temperature through evaporative cooling with a 4-pin PWM fan.
The system shall keep all critical temperature-control functions local to the
ESP32 and use Wi-Fi/MQTT only for observability, OTA firmware delivery, and
non-critical remote configuration.
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

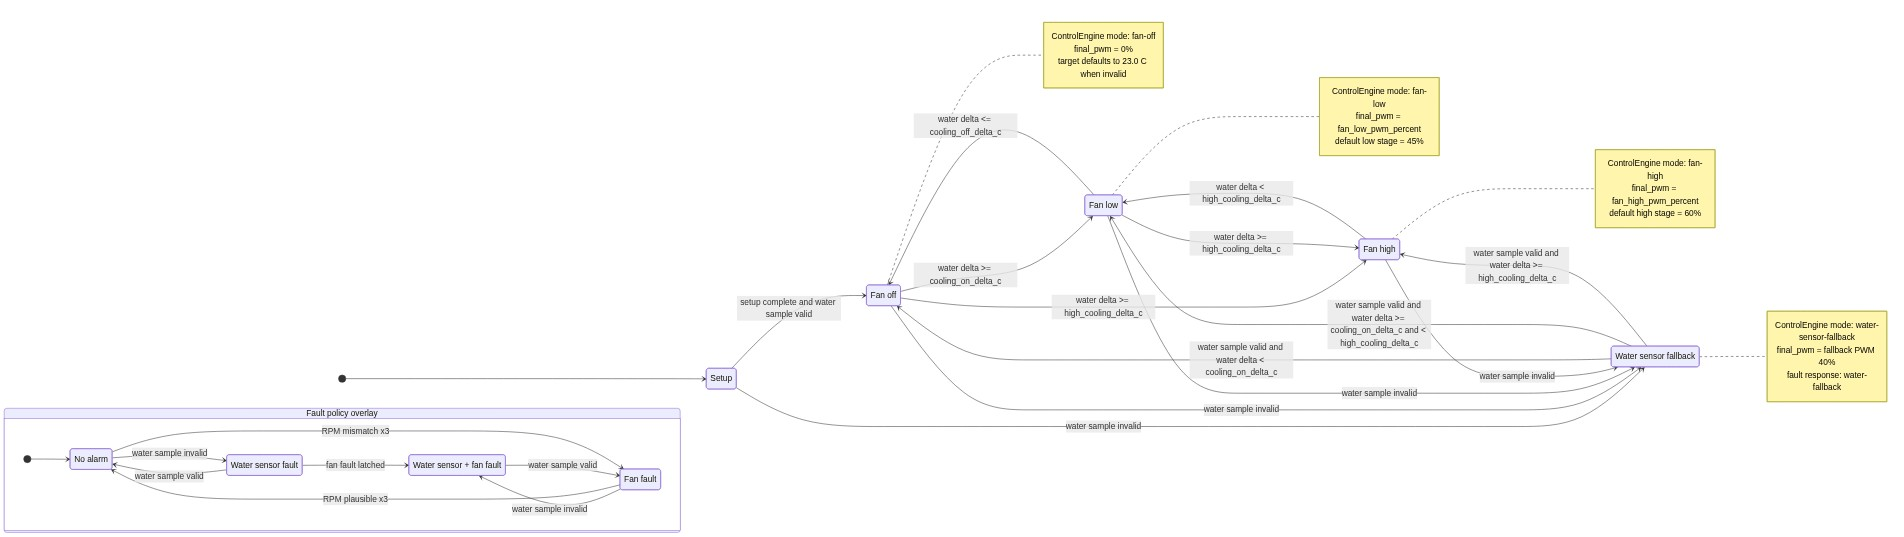
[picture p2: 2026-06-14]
docs/design/rendered/controller-state-machine.png

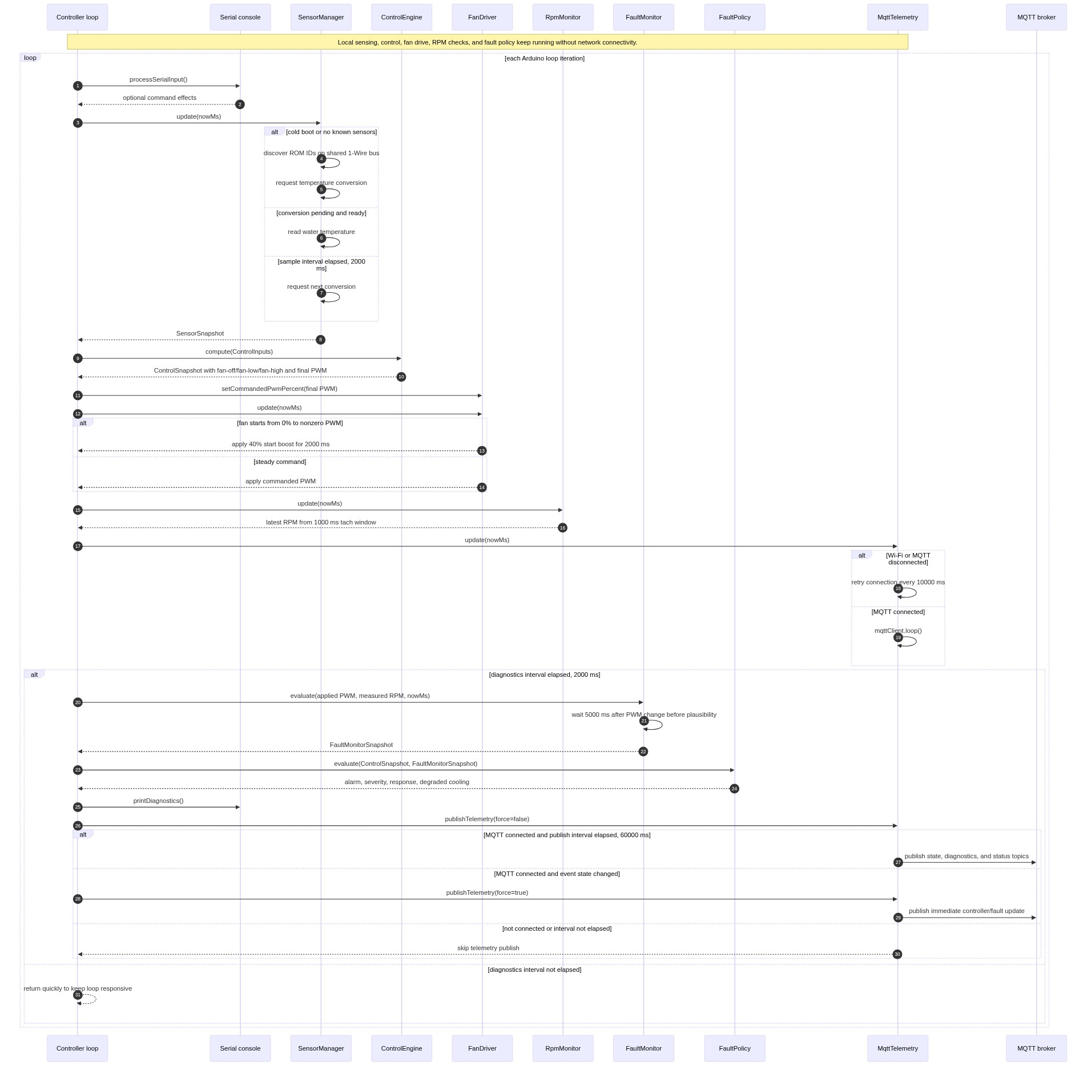
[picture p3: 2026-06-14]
docs/design/rendered/controller-cycle-sequence.png

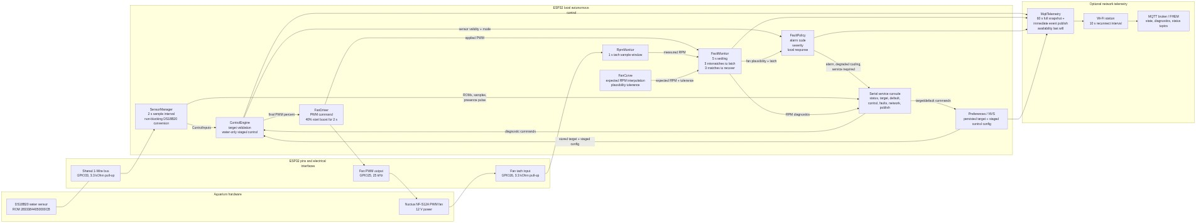
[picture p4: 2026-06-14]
docs/design/rendered/controller-system-architecture.png

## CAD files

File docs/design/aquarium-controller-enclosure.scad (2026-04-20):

/*
 * Aquarium Cooling Controller - parametric enclosure draft
 *
 * Orientation in this model:
 * - X axis: left/right while looking at the mounted enclosure
 * - Y axis: bottom/top while looking at the mounted enclosure
 * - Z axis: depth/protrusion away from the aquarium rear wall
 *
 * Port layout:
 * - USB-C power input exits downward through the bottom edge
 * - Fan connector/cable exits left
 * - Temperature sensor connector/cables exit right
 *
 * Print/export:
 * - Set part = "base" and export STL for the base
 * - Set part = "lid" and export STL for the lid
 * - part = "assembly" previews both parts and translucent component envelopes
 */

part = "assembly"; // "assembly", "base", "lid"
part_id = 0;        // CLI-friendly: 0 = assembly, 1 = base, 2 = lid

$fn = 36;

// ---------------------------------------------------------------------------
// Main enclosure parameters
// ---------------------------------------------------------------------------

wall = 2.8;              // PETG/PLA friendly wall thickness
floor_thickness = 2.8;
inner_x = 96;            // internal left/right space
inner_y = 78;            // internal bottom/top space
inner_z = 24;            // internal usable height
corner_radius = 4;

outer_x = inner_x + 2 * wall;
outer_y = inner_y + 2 * wall;
outer_z = inner_z + floor_thickness;

lid_thickness = 2.4;
lid_lip_height = 5;
lid_lip_thickness = 1.4;
lid_fit_gap = 0.35;

// M3 self-tapping screws into printed bosses. For threaded inserts, increase
// boss_outer_d and adapt screw_hole_d to the insert maker's recommendation.
screw_hole_d = 2.8;
screw_clearance_d = 3.3;
screw_counterbore_d = 6.2;
boss_outer_d = 8.0;
boss_offset = 7.5;
boss_height = inner_z - lid_lip_height - 0.8;

// Component envelopes. Tune these after measuring the exact modules.
esp32_x = 55;            // ESP32 DevKitC V4, assumed board length
esp32_y = 28;            // ESP32 DevKitC V4, assumed board width
esp32_h = 14;            // board + headers/component allowance

pd_x = 27;               // USB-C PD trigger board
pd_y = 11;
pd_h = 7;

buck_x = 20;             // 12 V -> 5 V buck converter
buck_y = 11;
buck_h = 9;

// JST/cable windows. These are connector-family dependent; measure and tune.
usb_cutout_x = 13.5;
usb_cutout_z = 8.0;
fan_cutout_y = 16;
fan_cutout_z = 9;
temp_cutout_y = 10;
temp_cutout_z = 8;
port_bottom_z = floor_thickness + 4;

// Board positions inside the box, in internal coordinates.
esp32_cx = inner_x / 2;
esp32_cy = 44;
pd_cx = inner_x / 2;
pd_cy = 10;
buck_cx = inner_x / 2;
buck_cy = 70;

fan_port_cy = 44;
temp_port_1_cy = 35;
temp_port_2_cy = 53;
usb_port_cx = pd_cx;

// Rails are used instead of relying on ESP32 mounting holes, which vary
// between DevKit-style boards and clones.
rail_height = 3.2;
rail_width = 2.0;
rail_clearance = 0.7;
end_stop = 2.0;

show_component_envelopes = true;
emboss_lid_labels = true;

// ---------------------------------------------------------------------------
// Utility modules
// ---------------------------------------------------------------------------

module rounded_box(size, r) {
    x = size[0];
    y = size[1];
    z = size[2];
    hull() {
        for (px = [r, x - r])
            for (py = [r, y - r])
                translate([px, py, 0])
                    cylinder(h = z, r = r);
    }
}

module screw_positions() {
    for (p = [
        [wall + boss_offset, wall + boss_offset],
        [outer_x - wall - boss_offset, wall + boss_offset],
        [wall + boss_offset, outer_y - wall - boss_offset],
        [outer_x - wall - boss_offset, outer_y - wall - boss_offset]
    ]) {
        translate([p[0], p[1], 0])
            children();
    }
}

module board_rails(cx, cy, sx, sy) {
    x0 = wall + cx - sx / 2;
    y0 = wall + cy - sy / 2;

    // Side rails along the long direction of the component envelope.
    translate([x0 - rail_width - rail_clearance, y0, floor_thickness])
        cube([rail_width, sy, rail_height]);
    translate([x0 + sx + rail_clearance, y0, floor_thickness])
        cube([rail_width, sy, rail_height]);

    // Small end stops so boards cannot slide out of the rails.
    translate([x0 - rail_width - rail_clearance, y0 - end_stop, floor_thickness])
        cube([sx + 2 * (rail_width + rail_clearance), end_stop, rail_height]);
    translate([x0 - rail_width - rail_clearance, y0 + sy, floor_thickness])
        cube([sx + 2 * (rail_width + rail_clearance), end_stop, rail_height]);
}

module connector_keepout(cx, cy, sx, sy, h) {
    translate([wall + cx - sx / 2, wall + cy - sy / 2, floor_thickness + 0.2])
        cube([sx, sy, h]);
}

module port_windows() {
    // Bottom USB-C opening, aligned with the PD trigger board.
    translate([
        wall + usb_port_cx - usb_cutout_x / 2,
        -1,
        port_bottom_z
    ])
        cube([usb_cutout_x, wall + 2, usb_cutout_z]);

    // Left fan connector/cable opening.
    translate([
        -1,
        wall + fan_port_cy - fan_cutout_y / 2,
        port_bottom_z
    ])
        cube([wall + 2, fan_cutout_y, fan_cutout_z]);

    // Right temperature sensor openings.
    for (cy = [temp_port_1_cy, temp_port_2_cy]) {
        translate([
            outer_x - wall - 1,
            wall + cy - temp_cutout_y / 2,
            port_bottom_z
        ])
            cube([wall + 2, temp_cutout_y, temp_cutout_z]);
    }
}

module base_shell() {
    difference() {
        rounded_box([outer_x, outer_y, outer_z], corner_radius);

        translate([wall, wall, floor_thickness])
            rounded_box(
                [inner_x, inner_y, inner_z + 1],
                max(corner_radius - wall, 0.2)
            );
    }
}

module base() {
    difference() {
        union() {
            base_shell();

            // Lid screw bosses.
            screw_positions()
                translate([0, 0, floor_thickness])
                    cylinder(h = boss_height, d = boss_outer_d);

            // Internal component rails.
            board_rails(esp32_cx, esp32_cy, esp32_x, esp32_y);
            board_rails(pd_cx, pd_cy, pd_x, pd_y);
            board_rails(buck_cx, buck_cy, buck_x, buck_y);

            // Small internal cable-tie/strain-relief saddles near the side exits.
            translate([wall + 5, wall + fan_port_cy - 12, floor_thickness])
                cube([3, 24, 5]);
            translate([outer_x - wall - 8, wall + temp_port_1_cy - 6, floor_thickness])
                cube([3, 12, 5]);
            translate([outer_x - wall - 8, wall + temp_port_2_cy - 6, floor_thickness])
                cube([3, 12, 5]);
        }

        port_windows();

        // Pilot holes in the base bosses.
        screw_positions()
            translate([0, 0, floor_thickness - 0.2])
                cylinder(h = boss_height + 0.5, d = screw_hole_d);

        // Cable-tie slots through the internal saddles.
        translate([wall + 4.5, wall + fan_port_cy - 8, floor_thickness + 1.8])
            cube([4, 16, 2.2]);
        translate([outer_x - wall - 8.5, wall + temp_port_1_cy - 4, floor_thickness + 1.8])
            cube([4, 8, 2.2]);
        translate([outer_x - wall - 8.5, wall + temp_port_2_cy - 4, floor_thickness + 1.8])
            cube([4, 8, 2.2]);
    }
}

module lid_lip() {
    lip_x = inner_x - 2 * lid_fit_gap;
    lip_y = inner_y - 2 * lid_fit_gap;
    inner_lip_x = lip_x - 2 * lid_lip_thickness;
    inner_lip_y = lip_y - 2 * lid_lip_thickness;

    translate([wall + lid_fit_gap, wall + lid_fit_gap, -lid_lip_height])
        difference() {
            rounded_box([lip_x, lip_y, lid_lip_height], max(corner_radius - wall, 0.2));
            translate([lid_lip_thickness, lid_lip_thickness, -0.1])
                rounded_box(
                    [inner_lip_x, inner_lip_y, lid_lip_height + 0.2],
                    max(corner_radius - wall - lid_lip_thickness, 0.2)
                );
        }
}

module lid_labels() {
    if (emboss_lid_labels) {
        linear_extrude(height = 0.55) {
            translate([wall + 6, wall + fan_port_cy - 4])
                rotate([0, 0, 90])
                    text("FAN", size = 5, halign = "center", valign = "center");
            translate([outer_x - wall - 6, wall + 44])
                rotate([0, 0, -90])
                    text("TEMP", size = 5, halign = "center", valign = "center");
            translate([wall + usb_port_cx, wall + 7])
                text("USB-C", size = 5, halign = "center", valign = "center");
        }
    }
}

module lid() {
    difference() {
        union() {
            rounded_box([outer_x, outer_y, lid_thickness], corner_radius);
            lid_lip();
            translate([0, 0, lid_thickness])
                lid_labels();
        }

        // M3 clearance holes through the lid.
        screw_positions()
            translate([0, 0, -lid_lip_height - 0.2])
                cylinder(h = lid_lip_height + lid_thickness + 1, d = screw_clearance_d);
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

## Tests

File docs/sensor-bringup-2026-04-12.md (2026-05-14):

# Sensor Bring-Up - 2026-04-12

> Historical note:
> This bring-up note records the original two-sensor bench wiring and ROM-ID
> validation session. The active firmware architecture later dropped the air
> sensor from the control path and now only requires the fixed water sensor for
> normal operation.

## Ergebnis

Zwei DS18B20 erfolgreich am Controller erkannt und fest per ROM-ID zugeordnet.

## Testaufbau

- ESP32 GPIO: `33`
- Pull-up: `3.3 kOhm` nach `3.3 V`
- Versorgung: `3.3 V`

## Ermittelte Leitungsbelegung

- `rot` -> `3.3 V`
- `gelb` -> `GND`
- `gruen` -> `DATA`

## Erkannte Sensordaten

- ROM-ID: `28333844050000CB`
- Gemessene Temperatur beim Test: ca. `25.69 C` bis `25.75 C`

## Zweiter Bus-Test am 2026-04-14

- Zweiter DS18B20 erfolgreich am selben 1-Wire-Bus auf `GPIO33` erkannt
- Luftsensor-ROM-ID: `28244644050000DA`
- Busdiagnostik zeigte zwei gefundene Sensoren
- Wassersensor-ROM `28333844050000CB` blieb stabil zugeordnet
- Gemessene Temperaturen beim Zwei-Sensor-Test: ca. `24.44 C` fuer Wasser und `24.31 C` bis `24.44 C` fuer Luft

## Firmware-Stand

- `sensor_manager` auf `OneWire` + `DallasTemperature` umgestellt
- Wassersensor per fester ROM-ID im Controller hinterlegt
- Luftsensor per fester ROM-ID im Controller hinterlegt
- Beide Sensoren laufen am gemeinsamen 1-Wire-Bus auf `GPIO33`

## Folge-Stand vom 2026-04-14

- Lokale Wasserregelung erfolgreich auf echter Hardware verifiziert
- Luft-Assist erfolgreich auf echter Hardware verifiziert
- Default-Wassertemperatur ist `23.0 C`
- `23.0 C` bleibt auch der Fehler- und Rueckfallwert bei ungueltigem Zielwert
- Benutzerdefinierte Zieltemperatur wird in ESP32 `Preferences` / NVS gespeichert
- Nach Reboot wird ein gueltiger gespeicherter Zielwert wieder geladen
- Nach ungueltigem Zielwert wird der gespeicherte Wert geloescht und beim naechsten Boot wieder `23.0 C` verwendet

## Aktuelle Service-Kommandos

- `status`
- `target <c>`
- `default`
- `airassist`
- `help`

## Lokale Artefakte

Die zugehoerigen Serienmitschnitte liegen lokal im ignorierten `build/`-Ordner:

- `build/sensor-bringup-serial-after-rewire.txt`
- `build/water-sensor-fixed-rom.txt`
- `build/two-sensor-scan-v3.txt`
- `build/air-sensor-assigned.txt`
- `build/persistence-and-faults.txt`
- `build/persistence-after-reboot.txt`
- `build/fallback-after-invalid-target.txt`

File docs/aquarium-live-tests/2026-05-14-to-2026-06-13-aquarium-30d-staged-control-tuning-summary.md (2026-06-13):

# Aquarium Live Test - 2026-05-14 to 2026-06-13

## Scope

First longer installed run after the cutover to firmware `0.1.6`.

This export does not represent one static tuning point. It captures the first
month of the staged water-only controller while the active PWM stages were tuned
live over MQTT.

Raw export:

- `docs/aquarium-live-tests/2026-05-14-to-2026-06-13-aquarium-30d-staged-control-tuning-fhem-export.csv`

Known aquarium light schedule during this phase:

- light on: `15:00`
- light off: `22:00`

## Capture Window

| Item | Value |
|---|---:|
| First sample | `2026-05-14 11:03:27` |
| Last sample | `2026-06-13 11:12:23` |
| Window length | `30.0 d` |
| Export rows | `52896` |
| Firmware transition in log | `0.1.5 -> 0.1.6` on `2026-05-14 11:53:40` |
| Logging gaps > 1 h | `0` |

## Important Context

This log contains a real tuning period, not just a passive observation run.

The active live controller at the end of the capture confirmed:

- `target_temp_c = 24.0`
- `cooling_on_delta_c = +0.5 C`
- `cooling_off_delta_c = -0.5 C`
- `high_cooling_delta_c = +1.0 C`
- `fan_low_pwm_percent = 45`
- `fan_high_pwm_percent = 60`
- `firmware_version = 0.1.6`

The export also still contains a few legacy MQTT status/state topics such as
`air_assist_enable`, `air_min_pwm_percent`, and `air_sensor_ok`, even though the
active control strategy is already water-only.

## Overall Observation

As one aggregate dataset, the month is too mixed to judge one single operating
point:

| Signal | Value |
|---|---:|
| Water temperature min / mean / max | `19.2 / 24.02 / 27.4 C` |
| Fan PWM sample mean | `22.06%` |
| Observed fan runtime | `43.32%` |
| Fan starts / stops | `26 / 26` |

The extreme water values are not representative of normal control behavior and
almost certainly include maintenance or disturbance events. The useful
conclusion comes from separating the month into tuning phases.

## Phase Breakdown

### Phase A - Initial `0.1.6` defaults (`22 / 35`)

Window:

- `2026-05-14 11:53:40` to `2026-05-27 17:09:14`

Behavior:

- observed PWM levels: `0`, `22`, `35`, rare short spikes to `60/80/100`
- control modes: `fan-off`, `fan-low`, `fan-high`
- no observed fan faults

Results:

| Signal | Value |
|---|---:|
| Water mean (filtered `>= 22 C`) | `24.00 C` |
| Water band `23.5 .. 24.5 C` | `47.22%` |
| Water above `24.5 C` | `26.71%` |
| Observed runtime | `37.28%` |
| Longest continuous run | `96.99 h` |
| Fan-fault events | `0` |

Interpretation:

- the staged architecture itself worked
- thermals were still too warm too often
- `22 / 35` was robust but too conservative

### Phase B - Intermediate `40%` tuning window

Window:

- `2026-05-27 17:09:15` to `2026-05-31 21:34:10`

Behavior:

- observed PWM levels: `0`, `40`
- only `fan-off` and `fan-low` were meaningfully active

Results:

| Signal | Value |
|---|---:|
| Water mean | `24.05 C` |
| Water band `23.5 .. 24.5 C` | `100%` |
| Observed runtime | `71.55%` |
| Longest continuous run | `53.72 h` |
| Fan-fault events | `37` |

Interpretation:

- thermally excellent
- diagnostically noisy
- too much runtime and too many plausibility faults

### Phase C - Stabilized `45 / 60` field tuning

Window:

- `2026-05-31 21:34:11` to `2026-06-13 11:12:23`

Behavior:

- observed PWM levels: mainly `0` and `45`, one short `60`
- almost all active cooling happened in `fan-low`

Results:

| Signal | Value |
|---|---:|
| Water mean (filtered `>= 22 C`) | `24.05 C` |
| Water band `23.5 .. 24.5 C` | `99.59%` |
| Water below `23.5 C` | `0.24%` |
| Water above `24.5 C` | `0.17%` |
| Observed runtime | `40.35%` |
| Longest continuous run | `13.67 h` |
| Fan-fault events | `1` |

Interpretation:

- this was the best overall operating point of the month
- water stayed almost perfectly in the desired band
- runtime was far lower than the old `0.1.5` `22%` phase
- the remaining fault behavior was negligible in practice

## Comparison to the Last Archived `0.1.5` Reference

Reference run:

- `docs/aquarium-live-tests/2026-05-02-to-2026-05-13-aquarium-11d-water-only-22pct-summary.md`

Comparison against the best `0.1.6` phase (`45 / 60`):

| Signal | `0.1.5` fixed `22%` | `0.1.6` tuned `45 / 60` |
|---|---:|---:|
| Water mean | `24.11 C` | `24.05 C` |
| Water band `23.5 .. 24.5 C` | `93.5%` | `99.59%` |
| Observed runtime | `85.4%` | `40.35%` |
| Fan faults | `0` | `1` |

This was a major field improvement:

- tighter water control
- far less fan runtime
- still practically fault-free

## Conclusions

This month-long export supported four key conclusions:

1. The staged `0.1.6` water-only architecture was the right direction.
2. The original `22 / 35` defaults were still too weak for the installed
   aquarium.
3. The intermediate `40%` experiment was too aggressive and triggered too many
   plausibility faults.
4. The later live-tuned `45 / 60` combination was the best observed operating
   point and should be treated as the current field baseline unless later runs
   prove otherwise.

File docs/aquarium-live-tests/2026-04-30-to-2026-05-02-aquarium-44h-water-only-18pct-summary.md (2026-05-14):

# Aquarium Live Test - 2026-04-30 to 2026-05-02

## Scope

First installed run of the simplified water-only hysteresis firmware after the
cutover on `2026-04-30 23:23:21`.

This phase still used a single active cooling stage of `18% PWM`.

Raw export:

- `docs/aquarium-live-tests/2026-04-30-to-2026-05-02-aquarium-44h-water-only-18pct-fhem-export.csv`

Known aquarium light schedule during this phase:

- light on: `15:00`
- light off: `22:00`

## Capture Window

| Item | Value |
|---|---:|
| First sample | `2026-04-30 23:24:31` |
| Last sample | `2026-05-02 19:35:01` |
| Duration | `44.2 h` |
| Export rows | `23366` |
| Firmware observed in log | `0.1.4` |

## Key Results

This run confirmed that the first water-only hysteresis controller was much
calmer than the earlier air-assist generation, but also showed that `18% PWM`
was too weak as the only active cooling stage.

### Water and Air

| Signal | Min | Max | Mean |
|---|---:|---:|---:|
| Water temperature | `23.8 C` | `24.6 C` | `24.18 C` |
| Air temperature | `23.1 C` | `34.1 C` | `27.29 C` |

Phase split:

| Phase | Water mean | Air mean | Fan PWM sample mean |
|---|---:|---:|---:|
| Light on (`15:00-22:00`) | `24.31 C` | `32.52 C` | `18.00%` |
| Light off | `24.14 C` | `24.49 C` | `17.67%` |

## Fan Runtime Observation

Observed PWM values were effectively binary in this phase:

- `0%`
- `18%`

Estimated runtime from sampled PWM intervals:

| Signal | Value |
|---|---:|
| Observed fan runtime | `92.0%` |
| Starts | `2` |
| Stops | `1` |
| Longest continuous run | `1716.2 min` |

This was the decisive result of the run: the controller was quiet and stable,
but the fan stayed active far too long for the available cooling reserve.

## Fault Observation

The known low-PWM plausibility issue was already much smaller than before, but
not yet fully gone:

| Signal | Value |
|---|---:|
| Observed fan-fault time | `8.3 min` |
| Observed fan-fault share | `0.32%` |

## Interpretation

This log led directly to the next tuning step:

1. The water-only strategy itself was confirmed.
2. The fixed low stage of `18%` was judged too weak.
3. The next firmware iteration should keep the same hysteresis but raise the
   active cooling stage.

## Follow-Up

This phase ends with the later cutover to the stronger fixed cooling stage:

- cutover to `22%` water-only low stage: `2026-05-02 21:56:23`

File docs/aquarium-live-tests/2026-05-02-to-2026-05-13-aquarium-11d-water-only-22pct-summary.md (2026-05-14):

# Aquarium Live Test - 2026-05-02 to 2026-05-13

## Scope

Longer installed run after raising the fixed water-only cooling stage from
`18%` to `22% PWM`.

Raw export:

- `docs/aquarium-live-tests/2026-05-02-to-2026-05-13-aquarium-11d-water-only-22pct-fhem-export.csv`

Known aquarium light schedule during this phase:

- light on: `15:00`
- light off: `22:00`

## Capture Window

| Item | Value |
|---|---:|
| First sample | `2026-05-02 21:56:23` |
| Last sample | `2026-05-13 22:14:47` |
| Window length | `264.3 h` |
| Export rows | `80232` |
| Firmware observed in log | `0.1.5` |
| Largest logging gap | `175340 s` (`48.7 h`) |

## Known Data Limitation

This export contains several FHEM-side logging interruptions. The thermals are
still interpretable, but runtime percentages should be read as observed sampled
behavior, not as perfectly gap-free wall-clock runtime.

## Key Results

This run was the first one that looked broadly right in practice:

- water stayed in the desired aquarium band
- the stronger stage reduced the need for near-permanent running
- observed fan faults disappeared

### Water and Air

| Signal | Min | Max | Mean |
|---|---:|---:|---:|
| Water temperature | `23.5 C` | `24.8 C` | `24.11 C` |
| Air temperature | `22.0 C` | `35.6 C` | `26.87 C` |

Phase split:

| Phase | Water mean | Air mean | Fan PWM sample mean |
|---|---:|---:|---:|
| Light on (`15:00-22:00`) | `24.20 C` | `31.48 C` | `18.05%` |
| Light off | `24.07 C` | `24.48 C` | `17.86%` |

## Fan Runtime Observation

Observed PWM values remained effectively binary in this phase:

- `0%`
- `22%`

Estimated runtime from sampled PWM intervals:

| Signal | Value |
|---|---:|
| Observed fan runtime | `85.4%` |
| Starts | `5` |
| Stops | `4` |

Compared with the previous `18%` phase, this was the more balanced operating
point.

## Fault Observation

The low-PWM plausibility issue was effectively gone in this observed run:

| Signal | Value |
|---|---:|
| Observed fan-fault time | `0.0 min` |
| Observed fan-fault share | `0.00%` |

## Interpretation

This export supported three important conclusions:

1. `22% PWM` is clearly the better fixed low stage than `18%`.
2. The water-only hysteresis concept was confirmed again.
3. A next tuning step should focus on staged control flexibility rather than
   bringing the old air-assist path back.

Those conclusions directly motivated the later `0.1.6` architecture update with
remote-configurable staged control parameters.

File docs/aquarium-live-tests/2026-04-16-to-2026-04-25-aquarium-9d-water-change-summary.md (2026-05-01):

# Aquarium Live Test - 2026-04-16 to 2026-04-25

## Scope

Longer multi-day aquarium FHEM/DB export covering the first installed control
phase, including the later water-change event on `2026-04-25`.

Raw export:

- `docs/aquarium-live-tests/2026-04-16-to-2026-04-25-aquarium-9d-water-change-fhem-export.csv`

Known aquarium light schedule during this phase:

- light on: `15:00`
- light off: `22:00`

Water change on `2026-04-25`:

- lid opened
- filter switched off
- water drained until the temperature probe was eventually no longer submerged
- cooler tap water added
- filter switched on again
- lid closed

## Capture Window

| Item | Value |
|---|---:|
| First sample | `2026-04-16 18:04:13` |
| Last sample | `2026-04-25 19:45:55` |
| Duration | `217.7 h` |
| Export rows | `188497` |

## Key Results

The long run shows that the controller kept the aquarium water stable over
multiple days, but also confirmed that the original air-assist path could keep
the fan running even when water was already below the intended target band.

### Stable Multi-Day Window

For the regular operating window before the water-change disturbance
(`2026-04-18` to `2026-04-24`), the water signal stayed tightly grouped:

| Signal | Min | Max | Mean | Median | Notes |
|---|---:|---:|---:|---:|---|
| Water temperature | `23.44 C` | `24.38 C` | `24.17 C` | `24.19 C` | Stable around the expected `24 C` target |
| Air temperature | `23.31 C` | `29.38 C` | `25.56 C` | n/a | Strongly follows lid heating and room conditions |
| Fan PWM | `0%` | n/a | `12.53%` | `12%` | Fan active often, even in otherwise stable operation |

### Light-On vs Light-Off Behavior

Within that same stable window:

| Phase | Water mean | Air mean | Fan PWM mean | Notes |
|---|---:|---:|---:|---|
| Light on (`15:00-22:00`) | `24.07 C` | `28.42 C` | `35.20%` | Air-assist kept airflow active against warm lid air |
| Light off | `24.20 C` | `24.20 C` | `6.82%` | Water was actually slightly warmer overnight |

Interpretation: the original control strategy clearly reduced warm lid air, but
it also tended to cool the water harder during the light phase than was really
necessary for the aquarium.

## Water Change Observation

The water change on `2026-04-25` appears very clearly in the export and should
be treated as an intentional disturbance, not as a normal control segment.

Key milestones:

| Event | Timestamp |
|---|---|
| Water falls below `24.0 C` | `2026-04-25 13:59:15` |
| Water falls below `23.0 C` | `2026-04-25 13:59:55` |
| Water falls below `22.0 C` | `2026-04-25 14:01:05` |
| Minimum water temperature | `2026-04-25 14:08:15` |

Minimum observed water temperature:

- `20.94 C`

This drop is too fast to represent the full `120 L` water mass alone. It is
consistent with the known maintenance workflow:

- sensor temporarily exposed or partially exposed to air
- very cold refill water locally near the probe
- reduced mixing while the filter was off

## Air-Assist Observation

The most important control observation from this export happened *after* the
water change:

| Timestamp | Observation |
|---|---|
| `2026-04-25 15:09:45` | `controller_mode = water-control+air-assist`, `fan_pwm_percent = 20`, `water_temp_c = 21.81 C` |

Interpretation: the fan resumed because warm lid air returned, even though the
water was still far below the intended target region. This strongly confirmed
that air temperature should not remain an equal control driver next to water
temperature.

## Fan / Plausibility Observation

The long run also reinforced the earlier plausibility finding: repeated
`fan_fault` intervals were mostly a low-PWM diagnostics problem, not evidence
of real repeated cooling failure.

The water stayed stable over days while these events occurred, which indicates a
plausibility/tolerance issue rather than a persistent mechanical fan fault.

## MQTT / Availability

Only short reconnect events were observed. No long network outage was seen that
would challenge local autonomous control.

## Current Interpretation

This export led to two important decisions:

1. Water temperature should remain the main control variable.
2. Air temperature may still be useful as telemetry, but not as a direct fan
   demand source in the main regulation path.

These findings motivated the later no-air-assist comparison run and, after that,
the switch to the newer water-only hysteresis firmware generation.

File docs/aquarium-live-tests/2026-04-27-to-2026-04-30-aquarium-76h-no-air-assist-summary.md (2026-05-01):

# Aquarium Live Test - 2026-04-27 to 2026-04-30

## Scope

Dedicated no-air-assist comparison run after disabling the old air-assist
contribution on `2026-04-27 16:48:41`.

Raw export:

- `docs/aquarium-live-tests/2026-04-27-to-2026-04-30-aquarium-76h-no-air-assist-fhem-export.csv`

Known aquarium light schedule during this phase:

- light on: `15:00`
- light off: `22:00`

## Capture Window

| Item | Value |
|---|---:|
| First sample | `2026-04-27 16:48:51` |
| Last sample | `2026-04-30 20:33:01` |
| Duration | `75.7 h` |
| Export rows | `68122` |

## Key Results

This run shows that the aquarium water stayed within an acceptable range even
without air-assist, but the lid air became much warmer during the light phase.

### Water Stability Without Air-Assist

Daily water ranges stayed moderate:

| Date | Water range | Mean | Notes |
|---|---:|---:|---|
| `2026-04-28` | `24.2 .. 24.5 C` | `24.35 C` | Stable |
| `2026-04-29` | `24.2 .. 24.8 C` | `24.41 C` | Slightly warmer than the earlier air-assist phase |
| `2026-04-30` | `24.2 .. 24.6 C` | `24.33 C` | Still within an acceptable aquarium band |

Interpretation: air-assist was not required to keep the water generally under
control.

## Comparison Against the Earlier Air-Assist Phase

Compared with the earlier stable air-assist window (`2026-04-18` to
`2026-04-24`):

### Light-On Phase (`15:00-22:00`)

| Mode | Water mean | Air mean | Fan PWM mean |
|---|---:|---:|---:|
| With air-assist | `24.07 C` | `28.42 C` | `35.20%` |
| Without air-assist | `24.45 C` | `32.32 C` | `18.02%` |

Difference without air-assist:

- water: about `+0.38 C`
- air: about `+3.89 C`
- fan PWM: about `-17.18` percentage points

### Night / Light-Off Phase

| Mode | Water mean | Air mean | Fan PWM mean |
|---|---:|---:|---:|
| With air-assist | `24.20 C` | `24.20 C` | `6.82%` |
| Without air-assist | `24.30 C` | `24.64 C` | `9.68%` |

Interpretation: the meaningful difference is mainly in the light phase, not at
night.

## Lid Air Observation

Without air-assist, the under-lid air got clearly hotter:

| Signal | Value |
|---|---:|
| Light-on air mean | `32.32 C` |
| Maximum air temperature | `35.8 C` |

This means air exchange does have a real physical effect. It just influences
the water much less strongly than it influences the air itself.

## Fan / Plausibility Observation

The known `fan_fault` topic did not disappear in the no-air-assist phase.
Fault intervals were still concentrated in the low-PWM region, especially
during light-off / low-demand operation.

Interpretation: low-PWM fan plausibility is a separate diagnostics issue and is
not caused by air-assist.

## Current Interpretation

This comparison run led to a clearer control conclusion:

1. Air-assist is not necessary to keep the water broadly stable.
2. Air-assist is effective at lowering warm lid air.
3. The old implementation gave air temperature too much authority over fan
   runtime.

That made a simpler water-led strategy the better next step:

- water remains the only active control input
- wider hysteresis is acceptable for the aquarium
- a quiet fixed fan stage is preferred over constant PWM reshaping

## Follow-Up

The next controller phase begins later on:

- cutover to water-only hysteresis firmware: `2026-04-30 23:23:21`

Subsequent log analysis should treat this file as the final pre-cutover
reference for the no-air-assist experiment.

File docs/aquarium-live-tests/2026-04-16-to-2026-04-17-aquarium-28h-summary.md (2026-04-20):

# Aquarium Live Test - 2026-04-16 to 2026-04-17

## Scope

Longer installed aquarium FHEM/DB export after the first 2 h live test.

Raw export:

- `docs/aquarium-live-tests/2026-04-16-to-2026-04-17-aquarium-28h-fhem-export.csv`

Known aquarium light schedule during this run:

- light on: `15:00`
- light off: `22:00`

## Capture Window

| Item | Value |
|---|---:|
| First sample | `2026-04-16 18:04:13` |
| Last sample | `2026-04-17 22:08:18` |
| Duration | `28.1 h` |
| Export rows | `25315` |

## Key Results

| Signal | First | Last | Min | Max | Notes |
|---|---:|---:|---:|---:|---|
| Water temperature | `26.56 C` | `23.19 C` | `23.19 C` | `26.62 C` | Strong real cooling effect |
| Air temperature | `29.12 C` | `26.31 C` | `21.75 C` | `29.12 C` | Lid air follows lighting strongly |
| Fan PWM | `86%` | `22%` | `0%` | `88%` | Demand dropped as water cooled |
| Fan RPM | `1230` | `360` | `0` | `1260` | RPM followed PWM overall |

The water/PWM relationship indicates an active target of about `24.0 C`.
The export did not contain regular `target_temp_c` samples, so this is inferred
from the control behavior.

## Water Temperature Milestones

| Threshold | First reached |
|---|---|
| `<= 26.0 C` | `2026-04-16 18:54:13` |
| `<= 25.0 C` | `2026-04-16 21:47:24` |
| `<= 24.5 C` | `2026-04-17 00:58:54` |
| `<= 24.0 C` | `2026-04-17 15:59:37` |
| `<= 23.5 C` | `2026-04-17 18:56:17` |

## Light Phase Summary

### 2026-04-16 Partial Light-On Phase

Capture segment: `18:04` to `22:00`.

| Signal | Start | End | Notes |
|---|---:|---:|---|
| Water temperature | `26.56 C` | `25.00 C` | Initial cooldown worked well |
| Air temperature | `28.75 C` | `28.50 C` | Lid air remained warm |
| Fan PWM | `86%` | `36%` | Demand fell as water approached target |
| Fan RPM | `1200` | `600` | Plausible with falling PWM |

### Night / Light-Off Phase

Capture segment: `2026-04-16 22:00` to `2026-04-17 15:00`.

| Signal | Start | End | Notes |
|---|---:|---:|---|
| Water temperature | `25.00 C` | `24.25 C` | Continued slow cooldown toward target |
| Air temperature | `28.50 C` | `23.38 C` | Lid air cooled after lights off |
| Fan PWM | `36%` | `12%` | Fan demand dropped, with some `0%` periods |
| Fan RPM | `600` | `0` | Low-PWM / stop region observed |

### 2026-04-17 Full Light-On Phase

Capture segment: `15:00` to `22:00`.

| Signal | Start | End | Notes |
|---|---:|---:|---|
| Water temperature | `24.25 C` | `23.19 C` | Water fell below target during light-on phase |
| Air temperature | `23.38 C` | `27.88 C` | Lid air warmed quickly after light on |
| Fan PWM | `12%` | `32%` | Air-assist drove fan demand |
| Fan RPM | `0` | `510` | Fan resumed as air assist increased |

During this light-on phase, water was below `24.0 C` while the fan still ran
for about `334 min`. This indicates that air-assist is effective against warm
lid air, but it can also continue cooling the water below the water target.

## Fault / Plausibility Observation

The export contains `66` fan-fault intervals totaling about `2240 s`
(`37.3 min`).

| Phase | Fault intervals | Total duration |
|---|---:|---:|
| Light on | `2` | `20 s` |
| Light off | `64` | `2220 s` |

The main fault cluster occurred during the morning low-PWM region around
`07:00` to `08:34` on `2026-04-17`.

Typical fault context:

| Signal | Typical range |
|---|---:|
| Fan PWM | `12% .. 14%` |
| Expected RPM | about `187 .. 223` |
| RPM tolerance | about `+/-22 .. +/-27` |
| Measured RPM | often `180`, `210`, or `240` |

Interpretation: the current plausibility check is too sensitive near the
minimum fan operating region. These events look like low-PWM tach quantization
or tolerance noise rather than real cooling failures.

Follow-up is tracked in GitHub issue `#1`.

## Air-Assist Observation

The second light-on phase shows that air-assist responds to warm lid air and
keeps airflow active. However, because water temperature continued to fall from
about `24.25 C` to `23.19 C`, future tuning should consider a water guard for
air-assist.

Potential future policy options:

- reduce air-assist when water is below target
- disable air-assist below `target - 0.2 C`
- cap air-assist PWM when water is already below target

This should not be changed immediately while OTA is unavailable. Continue
collecting installed logs first.

Follow-up is tracked in GitHub issue `#2`.

## MQTT / Availability

Only one short availability interruption was observed:

| Timestamp | Availability |
|---|---|
| `2026-04-17 03:58:11` | `offline` |
| `2026-04-17 03:58:17` | `online` |

This short 6 s reconnect is not concerning for local control.

## Logging Notes

The export still does not provide a complete periodic state reconstruction for
slow-changing retained values.

Missing or sparse readings in this export:

- `target_temp_c` was not present regularly
- `water_sensor_ok` was not present
- `air_sensor_ok` was not present
- `controller_mode` appeared only once

For future analysis, FHEM/DB logging should include periodic or heartbeat-style
records for target, mode, availability, and sensor health in addition to
change-driven event logs.

Follow-up is tracked in GitHub issue `#6`.

## Current Decision

Do not flash new firmware only for these observations. The installed system is
working and OTA is not available yet.

Keep collecting data with the current firmware and use the next planned
firmware update to address:

- low-PWM fan plausibility tolerance
- air-assist behavior when water is below target
- display precision / one-decimal temperature formatting

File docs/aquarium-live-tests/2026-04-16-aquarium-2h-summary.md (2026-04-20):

# Aquarium Live Test - 2026-04-16

## Scope

First real-aquarium FHEM/DB export after moving the controller from bench
verification to the installed aquarium test setup.

Raw export:

- `docs/aquarium-live-tests/2026-04-16-aquarium-2h-fhem-export.csv`

## Capture Window

| Item | Value |
|---|---:|
| First sample | `2026-04-16 18:04:13` |
| Last sample | `2026-04-16 20:10:44` |
| Duration | `126.5 min` |
| Export rows | `1951` |

## Logged Readings

The export is a FHEM long-format CSV with these columns:

```text
TIMESTAMP;DEVICE;TYPE;EVENT;READING;VALUE;UNIT
```

Observed readings in this export:

- `air_temp_c`
- `water_temp_c`
- `fan_pwm_percent`
- `fan_rpm`
- `expected_rpm`
- `rpm_tolerance`
- `rpm_error`
- `plausibility_active`
- `fan_plausible`
- `fan_fault`
- `alarm_code`
- `fault_severity`
- `fault_response`
- `cooling_degraded`
- `service_required`

## Key Results

| Signal | First | Last | Notes |
|---|---:|---:|---|
| Water temperature | `26.56 C` | `25.50 C` | About `-0.53 C/h` over the capture |
| Air temperature | `29.12 C` | `27.38 C` | Warm initial under-lid condition cooled down |
| Fan PWM | `86%` | `52%` | Controller reduced demand as water approached target |
| Fan RPM | `1230` | `810` | RPM followed the falling PWM demand |

The water-temperature and PWM relationship indicates an active target of about
`24.0 C` during this run.

## Fault / Plausibility Observation

One short fan-plausibility fault was recorded:

| Timestamp | Event |
|---|---|
| `2026-04-16 20:05:54` | `fan-fault`, `critical`, `report-fan-fault` |
| `2026-04-16 20:06:04` | recovered to `none`, `normal-control` |

The fault happened with measured RPM slightly above the expected curve plus
tolerance:

| Signal | Value |
|---|---:|
| Fan PWM | about `52%` |
| Expected RPM | `765` |
| RPM tolerance | `+/-92` |
| Measured RPM | `870` |
| RPM error | `+105` |

Interpretation: this looks more like an installed-airflow / tolerance mismatch
than a real cooling failure. The controller recovered automatically after the
next plausible match.

## Current Decision

Because the controller is already installed and OTA is not implemented yet, the
firmware will not be changed for this observation phase. Continue collecting
FHEM/DB logs with the current firmware and evaluate longer runs before changing
control or fault-monitor parameters.

Recommended next capture:

- at least `24 h`
- ideally `48-72 h`
- include target, controller mode, availability, fault status, PWM, RPM,
  expected RPM, RPM tolerance, water temperature, and air temperature

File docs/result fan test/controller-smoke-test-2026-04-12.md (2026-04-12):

# Controller Smoke Test

Date: `2026-04-12`

## Scope

First bench smoke test of the production-controller scaffold in
[`firmware/controller/`](../../firmware/controller/).

Validated areas:

- ESP32 compile and flash
- PWM output bring-up on `GPIO25`
- tachometer RPM measurement on `GPIO26`
- fan start-boost behavior
- fan-curve interpolation and plausibility diagnostics
- serial command handling for safe bench control

## Bench Setup

- Controller board: `ESP32`
- Fan: `Noctua NF-S12A PWM`
- PWM pin: `GPIO25`
- Tach pin: `GPIO26`
- Tach pull-up: `3.3 kOhm` to `3.3 V`
- PWM frequency: `25 kHz`
- Upload port: `COM3`

## Toolchain Observed During Test

- `arduino-cli` target: `esp32:esp32:esp32`
- active ESP32 Arduino core reported by the running firmware: `3.3.7`

Note:

- The Arduino IDE had reportedly been updated, but the actual core seen by
  `arduino-cli` and the device during this test was still `3.3.7`.

## Firmware Behavior Confirmed

- Controller booted successfully and printed the curve summary.
- Fan driver initialized successfully.
- RPM monitor initialized successfully.
- The controller started in a safe `0%` PWM state.
- Serial commands were available: `0..100`, `stop`, `status`, `help`.

## Interactive Fan Test

Test sequence:

1. Flash the controller scaffold.
2. Open the serial connection.
3. Send `15`.
4. Observe start-boost and tach feedback.
5. Send `stop`.

Observed results:

- `15%` target PWM was accepted.
- Start-boost activated at `40%` PWM.
- After boost, applied PWM settled to `15%`.
- Measured RPM settled near the characterized curve:
  - transient readings included `540 RPM` and `270 RPM`
  - stable reading converged to about `240 RPM`
- The expected interpolated RPM at `15%` was reported as `241 RPM`.
- `stop` returned the fan cleanly to `0 RPM`.

## Captured Serial Artifacts

- startup log:
  - [`controller-startup-2026-04-12.txt`](./controller-startup-2026-04-12.txt)

## Outcome

The first production-controller scaffold is confirmed to:

- compile and flash successfully
- control the fan safely from a stopped state
- measure tach RPM on real hardware
- produce useful plausibility diagnostics against the measured fan curve

## Recommended Next Step

Add the DS18B20 `sensor_manager` and replace manual serial PWM commands with the
first simple local temperature-based control path.

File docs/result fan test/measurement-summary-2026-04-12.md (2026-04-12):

# Fan Characterization Summary

Date: `2026-04-12`

Hardware under test:

- Fan: `Noctua NF-S12A PWM`
- Controller: `ESP32` using `GPIO25` for PWM and `GPIO26` for TACH
- Tach pull-up: `3.3 kOhm` to `3.3 V`
- PWM frequency: `25 kHz`

Important wiring note:

- The successful measurements were only achieved after correcting the ground wiring.
- `ESP32 GND`, `fan GND`, and `12 V supply GND` must share a common reference.

## Result Summary

| Metric | Value |
|---|---:|
| Start PWM from standstill | `12%` |
| Minimum hold PWM while spinning | `10%` |
| RPM at 0% PWM | `0` |
| RPM at 5% PWM | `0` |
| RPM at 100% PWM | `1252` |

## Curve Visualization

Measured fan curve

## Upward Curve

```cpp
FanCurvePoint curve[] = {
  {12, 187},
  {17, 277},
  {22, 352},
  {27, 435},
  {32, 517},
  {37, 570},
  {42, 637},
  {47, 697},
  {52, 765},
  {57, 832},
  {62, 885},
  {67, 930},
  {72, 997},
  {77, 1050},
  {82, 1102},
  {87, 1147},
  {92, 1185},
  {97, 1230},
  {100, 1252},
};
```

## Downward Curve

| PWM | RPM |
|---:|---:|
| 100 | 1237 |
| 95 | 1245 |
| 90 | 1140 |
| 85 | 1125 |
| 80 | 1095 |
| 75 | 1020 |
| 70 | 975 |
| 65 | 937 |
| 60 | 870 |
| 55 | 802 |
| 50 | 757 |
| 45 | 675 |
| 40 | 637 |
| 35 | 562 |
| 30 | 480 |
| 25 | 397 |
| 20 | 330 |
| 15 | 232 |
| 10 | 150 |
| 5 | 0 |
| 0 | 0 |

## Source Logs

- [`fan-curve-chart.svg`](./fan-curve-chart.svg)
- [`live-run.txt`](./live-run.txt)
- [`live-run-part2.txt`](./live-run-part2.txt)
- historical comparison:
  - [`with pullup.txt`](./with%20pullup.txt)
  - [`without pullup.txt`](./without%20pullup.txt)

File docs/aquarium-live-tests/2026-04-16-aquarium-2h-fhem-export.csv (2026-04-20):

TIMESTAMP | DEVICE | TYPE | EVENT | READING | VALUE | UNIT
2026-04-16 20:10:44 | wz_AquariumCooling | MQTT2_DEVICE | air_temp_c: 27.38 | air_temp_c | 27.38 | \N
2026-04-16 20:10:44 | wz_AquariumCooling | MQTT2_DEVICE | fan_rpm: 810 | fan_rpm | 810 | \N
2026-04-16 20:10:44 | wz_AquariumCooling | MQTT2_DEVICE | rpm_error: 45 | rpm_error | 45 | \N
2026-04-16 20:10:34 | wz_AquariumCooling | MQTT2_DEVICE | air_temp_c: 27.31 | air_temp_c | 27.31 | \N
2026-04-16 20:10:24 | wz_AquariumCooling | MQTT2_DEVICE | plausibility_active: true | plausibility_active | true | \N
2026-04-16 20:10:14 | wz_AquariumCooling | MQTT2_DEVICE | air_temp_c: 27.38 | air_temp_c | 27.38 | \N
2026-04-16 20:10:14 | wz_AquariumCooling | MQTT2_DEVICE | plausibility_active: false | plausibility_active | false | \N
2026-04-16 20:10:04 | wz_AquariumCooling | MQTT2_DEVICE | fan_rpm: 840 | fan_rpm | 840 | \N
2026-04-16 20:10:04 | wz_AquariumCooling | MQTT2_DEVICE | rpm_error: 75 | rpm_error | 75 | \N
2026-04-16 20:10:04 | wz_AquariumCooling | MQTT2_DEVICE | fan_plausible: true | fan_plausible | true | \N
2026-04-16 20:09:54 | wz_AquariumCooling | MQTT2_DEVICE | air_temp_c: 27.31 | air_temp_c | 27.31 | \N
2026-04-16 20:09:54 | wz_AquariumCooling | MQTT2_DEVICE | fan_rpm: 870 | fan_rpm | 870 | \N
2026-04-16 20:09:54 | wz_AquariumCooling | MQTT2_DEVICE | rpm_error: 105 | rpm_error | 105 | \N
2026-04-16 20:09:54 | wz_AquariumCooling | MQTT2_DEVICE | fan_plausible: false | fan_plausible | false | \N
2026-04-16 20:09:44 | wz_AquariumCooling | MQTT2_DEVICE | fan_rpm: 810 | fan_rpm | 810 | \N
2026-04-16 20:09:44 | wz_AquariumCooling | MQTT2_DEVICE | rpm_error: 45 | rpm_error | 45 | \N
2026-04-16 20:09:24 | wz_AquariumCooling | MQTT2_DEVICE | fan_rpm: 840 | fan_rpm | 840 | \N
2026-04-16 20:09:24 | wz_AquariumCooling | MQTT2_DEVICE | rpm_error: 75 | rpm_error | 75 | \N
2026-04-16 20:09:24 | wz_AquariumCooling | MQTT2_DEVICE | fan_plausible: true | fan_plausible | true | \N
2026-04-16 20:09:14 | wz_AquariumCooling | MQTT2_DEVICE | air_temp_c: 27.38 | air_temp_c | 27.38 | \N
2026-04-16 20:09:14 | wz_AquariumCooling | MQTT2_DEVICE | fan_rpm: 870 | fan_rpm | 870 | \N
2026-04-16 20:09:14 | wz_AquariumCooling | MQTT2_DEVICE | rpm_error: 105 | rpm_error | 105 | \N
2026-04-16 20:09:14 | wz_AquariumCooling | MQTT2_DEVICE | fan_plausible: false | fan_plausible | false | \N
2026-04-16 20:08:54 | wz_AquariumCooling | MQTT2_DEVICE | air_temp_c: 27.31 | air_temp_c | 27.31 | \N
2026-04-16 20:08:44 | wz_AquariumCooling | MQTT2_DEVICE | fan_rpm: 810 | fan_rpm | 810 | \N
2026-04-16 20:08:44 | wz_AquariumCooling | MQTT2_DEVICE | rpm_error: 45 | rpm_error | 45 | \N
2026-04-16 20:08:34 | wz_AquariumCooling | MQTT2_DEVICE | air_temp_c: 27.38 | air_temp_c | 27.38 | \N
2026-04-16 20:08:24 | wz_AquariumCooling | MQTT2_DEVICE | air_temp_c: 27.31 | air_temp_c | 27.31 | \N
2026-04-16 20:08:24 | wz_AquariumCooling | MQTT2_DEVICE | fan_rpm: 840 | fan_rpm | 840 | \N
2026-04-16 20:08:24 | wz_AquariumCooling | MQTT2_DEVICE | rpm_error: 75 | rpm_error | 75 | \N
2026-04-16 20:08:24 | wz_AquariumCooling | MQTT2_DEVICE | fan_plausible: true | fan_plausible | true | \N
2026-04-16 20:08:14 | wz_AquariumCooling | MQTT2_DEVICE | fan_rpm: 870 | fan_rpm | 870 | \N
2026-04-16 20:08:14 | wz_AquariumCooling | MQTT2_DEVICE | rpm_error: 105 | rpm_error | 105 | \N
2026-04-16 20:08:14 | wz_AquariumCooling | MQTT2_DEVICE | fan_plausible: false | fan_plausible | false | \N
2026-04-16 20:07:44 | wz_AquariumCooling | MQTT2_DEVICE | air_temp_c: 27.38 | air_temp_c | 27.38 | \N
2026-04-16 20:07:44 | wz_AquariumCooling | MQTT2_DEVICE | fan_rpm: 810 | fan_rpm | 810 | \N
2026-04-16 20:07:44 | wz_AquariumCooling | MQTT2_DEVICE | rpm_error: 45 | rpm_error | 45 | \N
2026-04-16 20:07:34 | wz_AquariumCooling | MQTT2_DEVICE | air_temp_c: 27.31 | air_temp_c | 27.31 | \N
2026-04-16 20:07:34 | wz_AquariumCooling | MQTT2_DEVICE | fan_rpm: 840 | fan_rpm | 840 | \N
2026-04-16 20:07:34 | wz_AquariumCooling | MQTT2_DEVICE | rpm_error: 75 | rpm_error | 75 | \N
2026-04-16 20:07:34 | wz_AquariumCooling | MQTT2_DEVICE | fan_plausible: true | fan_plausible | true | \N
2026-04-16 20:07:24 | wz_AquariumCooling | MQTT2_DEVICE | air_temp_c: 27.38 | air_temp_c | 27.38 | \N
2026-04-16 20:07:24 | wz_AquariumCooling | MQTT2_DEVICE | fan_rpm: 870 | fan_rpm | 870 | \N
2026-04-16 20:07:24 | wz_AquariumCooling | MQTT2_DEVICE | rpm_error: 105 | rpm_error | 105 | \N
2026-04-16 20:07:24 | wz_AquariumCooling | MQTT2_DEVICE | fan_plausible: false | fan_plausible | false | \N
2026-04-16 20:07:04 | wz_AquariumCooling | MQTT2_DEVICE | air_temp_c: 27.31 | air_temp_c | 27.31 | \N
2026-04-16 20:07:04 | wz_AquariumCooling | MQTT2_DEVICE | fan_rpm: 810 | fan_rpm | 810 | \N
2026-04-16 20:07:04 | wz_AquariumCooling | MQTT2_DEVICE | rpm_error: 45 | rpm_error | 45 | \N
2026-04-16 20:06:54 | wz_AquariumCooling | MQTT2_DEVICE | fan_rpm: 840 | fan_rpm | 840 | \N
2026-04-16 20:06:54 | wz_AquariumCooling | MQTT2_DEVICE | rpm_error: 75 | rpm_error | 75 | \N
2026-04-16 20:06:44 | wz_AquariumCooling | MQTT2_DEVICE | fan_rpm: 810 | fan_rpm | 810 | \N
2026-04-16 20:06:44 | wz_AquariumCooling | MQTT2_DEVICE | rpm_error: 45 | rpm_error | 45 | \N
2026-04-16 20:06:24 | wz_AquariumCooling | MQTT2_DEVICE | fan_rpm: 840 | fan_rpm | 840 | \N
2026-04-16 20:06:24 | wz_AquariumCooling | MQTT2_DEVICE | rpm_error: 75 | rpm_error | 75 | \N
2026-04-16 20:06:04 | wz_AquariumCooling | MQTT2_DEVICE | fan_rpm: 810 | fan_rpm | 810 | \N
2026-04-16 20:06:04 | wz_AquariumCooling | MQTT2_DEVICE | rpm_error: 45 | rpm_error | 45 | \N
2026-04-16 20:06:04 | wz_AquariumCooling | MQTT2_DEVICE | fan_plausible: true | fan_plausible | true | \N
2026-04-16 20:06:04 | wz_AquariumCooling | MQTT2_DEVICE | fan_fault: false | fan_fault | false | \N
2026-04-16 20:06:04 | wz_AquariumCooling | MQTT2_DEVICE | cooling_degraded: false | cooling_degraded | false | \N
2026-04-16 20:06:04 | wz_AquariumCooling | MQTT2_DEVICE | service_required: false | service_required | false | \N
2026-04-16 20:06:04 | wz_AquariumCooling | MQTT2_DEVICE | alarm_code: none | alarm_code | none | \N
2026-04-16 20:06:04 | wz_AquariumCooling | MQTT2_DEVICE | fault_severity: none | fault_severity | none | \N
2026-04-16 20:06:04 | wz_AquariumCooling | MQTT2_DEVICE | fault_response: normal-control | fault_response | normal-control | \N
2026-04-16 20:05:54 | wz_AquariumCooling | MQTT2_DEVICE | fan_rpm: 870 | fan_rpm | 870 | \N
2026-04-16 20:05:54 | wz_AquariumCooling | MQTT2_DEVICE | rpm_error: 105 | rpm_error | 105 | \N
2026-04-16 20:05:54 | wz_AquariumCooling | MQTT2_DEVICE | fan_plausible: false | fan_plausible | false | \N
2026-04-16 20:05:54 | wz_AquariumCooling | MQTT2_DEVICE | fan_fault: true | fan_fault | true | \N
2026-04-16 20:05:54 | wz_AquariumCooling | MQTT2_DEVICE | cooling_degraded: true | cooling_degraded | true | \N
2026-04-16 20:05:54 | wz_AquariumCooling | MQTT2_DEVICE | service_required: true | service_required | true | \N
2026-04-16 20:05:54 | wz_AquariumCooling | MQTT2_DEVICE | alarm_code: fan-fault | alarm_code | fan-fault | \N
2026-04-16 20:05:54 | wz_AquariumCooling | MQTT2_DEVICE | fault_severity: critical | fault_severity | critical | \N
2026-04-16 20:05:54 | wz_AquariumCooling | MQTT2_DEVICE | fault_response: report-fan-fault | fault_response | report-fan-fault | \N
2026-04-16 20:05:44 | wz_AquariumCooling | MQTT2_DEVICE | fan_rpm: 810 | fan_rpm | 810 | \N
2026-04-16 20:05:44 | wz_AquariumCooling | MQTT2_DEVICE | rpm_error: 45 | rpm_error | 45 | \N
2026-04-16 20:05:34 | wz_AquariumCooling | MQTT2_DEVICE | air_temp_c: 27.38 | air_temp_c | 27.38 | \N
2026-04-16 20:05:24 | wz_AquariumCooling | MQTT2_DEVICE | fan_rpm: 840 | fan_rpm | 840 | \N
2026-04-16 20:05:24 | wz_AquariumCooling | MQTT2_DEVICE | rpm_error: 75 | rpm_error | 75 | \N
2026-04-16 20:04:54 | wz_AquariumCooling | MQTT2_DEVICE | plausibility_active: true | plausibility_active | true | \N
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

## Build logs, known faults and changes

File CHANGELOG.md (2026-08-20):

# Changelog

All notable changes to this project will be documented in this file.

The format is based on [Keep a Changelog](https://keepachangelog.com/en/1.1.0/),
and this project adheres to [Semantic Versioning](https://semver.org/).

## [Unreleased]

## [0.3.0] - 2026-08-20

### Added

- Added optional local `0.91"` monochrome `128x32` `I2C` OLED support with a
  short `BOOT` start view, large one-decimal water-temperature rendering, and
  fault indication as `!` plus `WATER`, `FAN`, or `BOTH`.
- Added fail-open OLED diagnostics and runtime behavior so missing or failing
  display hardware does not affect local control, MQTT, or OTA.

### Changed

- Promoted the firmware version to `0.3.0`.
- Documented the released OLED wiring on GPIO32 / GPIO27 and updated README,
  FSD, design notes, and integration documentation for the completed display
  feature set.

## [0.2.0] - 2026-06-14

### Added

- Added staged water-only cooling with `fan-off`, `fan-low`, `fan-high`, and
  `water-sensor-fallback` controller modes.
- Added persisted MQTT remote configuration for target temperature, hysteresis
  deltas, low/high fan stages, and OTA enablement.
- Added MQTT-visible OTA status, controller IP, upload URL, remote-config
  result readings, and firmware version reporting.
- Added `tools/ota-upload.ps1` as the standard OTA flashing workflow for the
  installed controller.
- Added a field-tested FHEM `MQTT2_DEVICE` profile with status display,
  set commands, DBLog include list, and long-running event throttling.

### Changed

- Promoted the firmware version to `0.2.0`.
- Made water temperature the active control variable and removed the active
  air-sensor control path from the current firmware.
- Set the default staged fan levels to `45%` for `fan-low` and `60%` for
  `fan-high`.
- Changed MQTT full telemetry snapshots to a 60-second baseline with immediate
  publishes for relevant controller, fault, and accepted remote-config changes.
- Reworked the README into a user-facing product guide and moved historical
  development detail out of the main project path.
- Updated FHEM documentation to use the current live profile:
  `event-on-change-reading .*`, `event-min-interval .*:1800`, and
  `DbLogInclude water_temp_c:1800,target_temp_c:86400,fan_pwm_percent:300,controller_mode,fan_fault,alarm_code,fault_severity,fault_response,availability`.
- Standardized repository build and maintenance workflows on
  `tools/build.ps1`, `tools/mqtt-client.ps1`, and `tools/ota-upload.ps1`.

## [0.1.4] - 2026-05-01

### Added

- Added BIN-only OTA uploads through a temporary ESP32-hosted upload endpoint
  with serial `ota status`, `ota enable`, and `ota cancel` commands.
- Added explicit firmware identity and firmware-version tags inside the OTA
  image so OTA validation does not depend on Arduino `PROJECT_NAME` or ESP32
  build metadata.
- Added validated MQTT remote configuration with persistence and broker-visible
  feedback for accepted and rejected commands.
- Added retained MQTT status topics for `network_ip` and `ota_upload_url` so
  OTA can be discovered and targeted entirely through the broker-facing
  workflow.

### Changed

- Added MQTT control of the temporary OTA maintenance window and published OTA
  state/message topics plus the running firmware version for FHEM and
  broker-side observability.
- Updated the OTA specification to use a manual BIN-only ESP32 upload
  maintenance mode without ZIP archives, manifests, external update polling,
  passwords, or tokens.
- Hardened BIN-only OTA validation to reject incomplete uploads, confirm the
  freshly booted OTA image for rollback handling, and validate uploads against
  the intended firmware identity plus a newer SemVer release.
- Simplified steady-state control to water-only hysteresis behavior and removed
  the active auxiliary-air control path from the installed controller firmware.
- Documented the repository's canonical build artifact layout:
  `.arduino-build/` for working compilation state, `build/` for exported
  binaries and logs, and `firmware/controller/build/` as a disposable Arduino
  tooling artifact directory.
- Confirmed the BIN-only OTA workflow on ESP32 hardware, including MQTT
  enablement, upload endpoint publication, validation failure handling, reboot,
  and firmware `0.1.4` reporting.
- Rounded displayed and published temperature values to one decimal place at
  output boundaries while keeping internal control values at full floating-point
  precision.
- Updated the FHEM integration and project documentation for the new MQTT
  remote configuration surface and the one-decimal display convention.

## [0.1.0] - 2026-04-20

### Added

- Added the ESP32 aquarium cooling controller firmware baseline.
- Added local autonomous water-temperature control with DS18B20 sensing.
- Added fixed DS18B20 role mapping by ROM ID.
- 4-pin PWM fan control with start boost and measured fan-curve data.
- Tachometer RPM measurement and fan plausibility diagnostics.
- Fault policy for water-sensor and fan-plausibility faults.
- Preferences/NVS persistence for custom target temperature.
- Non-blocking Wi-Fi and publish-only MQTT telemetry.
- FHEM MQTT2 monitoring definition for the verified telemetry topic set.
- Project FSD, design diagrams, fan characterization notes, and field-test
  documentation.
- Changelog structure and documented SemVer / Keep a Changelog release
  policy.

[Unreleased]: https://github.com/TeeVau/aquarium-cooling-controller/compare/v0.3.0...HEAD
[0.3.0]: https://github.com/TeeVau/aquarium-cooling-controller/releases/tag/v0.3.0
[0.2.0]: https://github.com/TeeVau/aquarium-cooling-controller/releases/tag/v0.2.0
[0.1.4]: https://github.com/TeeVau/aquarium-cooling-controller/releases/tag/v0.1.4
[0.1.0]: https://github.com/TeeVau/aquarium-cooling-controller/releases/tag/v0.1.0

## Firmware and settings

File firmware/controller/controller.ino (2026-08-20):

/**
 * @file controller.ino
 * @brief Arduino sketch entry point for the aquarium cooling controller.
 *
 * The sketch wires the firmware modules together and owns the runtime loop. It
 * sets up persistent temperature-control storage, water-temperature
 * sensing, fan PWM output, tachometer RPM monitoring, fault evaluation, serial
 * diagnostics, and optional MQTT telemetry.
 *
 * Runtime behavior is locally autonomous by design: cooling control, fan safety
 * monitoring, and diagnostics continue on the ESP32 even when Wi-Fi, MQTT, or
 * external integrations are unavailable.
 *
 * @section controller_circuit Circuit
 *
 * - DS18B20 water probe on the shared OneWire bus.
 * - Four-wire PWM fan controlled by ESP32 LEDC output.
 * - Fan tachometer connected to an interrupt-capable ESP32 GPIO.
 *
 * @section controller_libraries Libraries
 *
 * - Arduino core for ESP32.
 * - Preferences for persisted target-temperature storage.
 * - OneWire and DallasTemperature through SensorManager.
 * - PubSubClient and WiFi through MqttTelemetry.
 *
 * @section controller_loop_order Main Loop Order
 *
 * - process serial commands,
 * - update sensor conversions,
 * - compute the fan PWM command,
 * - apply PWM and update start boost,
 * - update RPM sampling and MQTT connection state,
 * - periodically evaluate faults, print diagnostics, and publish telemetry.
 *
 * @section controller_serial Serial Commands
 *
 * The serial monitor exposes service commands for status output,
 * target-temperature changes, default reset, control defaults, fault-policy
 * settings, network status, and forced telemetry publishing.
 *
 * @section controller_notes Notes
 *
 * Keep this sketch focused on orchestration. Hardware abstractions and policy
 * decisions live in dedicated modules so Doxygen pages remain navigable and the
 * Arduino loop stays easy to audit.
 */

#include <Arduino.h>

#include <esp_arduino_version.h>
#include <esp_ota_ops.h>
#include <Preferences.h>

#include "control_engine.h"
#include "display_format.h"
#include "fan_driver.h"
#include "fan_curve.h"
#include "fault_monitor.h"
#include "fault_policy.h"
#include "mqtt_telemetry.h"
#include "oled_status_display.h"
#include "ota_upload_server.h"
#include "rpm_monitor.h"
#include "sensor_manager.h"

namespace {

#define AQ_FIRMWARE_VERSION "0.3.0"

constexpr char kFirmwareName[] = "aq-cooling-controller";
constexpr char kFirmwareVersion[] = AQ_FIRMWARE_VERSION;
constexpr char kFirmwareIdentityTag[] = "AQFW_PRODUCT=aq-cooling-controller";
constexpr char kFirmwareVersionTag[] = "AQFW_VERSION=" AQ_FIRMWARE_VERSION;
constexpr char kUnavailableText[] = "unavailable";
constexpr uint32_t kDiagnosticsIntervalMs = 2000;
constexpr size_t kSerialCommandBufferSize = 32;
constexpr size_t kSensorAddressBufferSize = 17;
constexpr size_t kWaterSensorIndex = 0;
constexpr size_t kNetworkIpBufferSize = 16;
constexpr size_t kOtaUploadUrlBufferSize = 40;
constexpr char kPreferencesNamespace[] = "controller";
constexpr char kKeyHasCustomTarget[] = "target_set";
constexpr char kKeyTargetTemperature[] = "target_c";
constexpr char kKeyCoolingOnDelta[] = "cool_on";
constexpr char kKeyCoolingOffDelta[] = "cool_off";
constexpr char kKeyHighCoolingDelta[] = "cool_high";
constexpr char kKeyFanLowPwm[] = "fan_low";
constexpr char kKeyFanHighPwm[] = "fan_high";
constexpr char kSetTargetTemperatureSuffix[] = "/set/target_temp_c";
constexpr char kSetCoolingOnDeltaSuffix[] = "/set/cooling_on_delta_c";
constexpr char kSetCoolingOffDeltaSuffix[] = "/set/cooling_off_delta_c";
constexpr char kSetHighCoolingDeltaSuffix[] = "/set/high_cooling_delta_c";
constexpr char kSetFanLowPwmSuffix[] = "/set/fan_low_pwm_percent";
constexpr char kSetFanHighPwmSuffix[] = "/set/fan_high_pwm_percent";
constexpr char kSetOtaEnableSuffix[] = "/set/ota_enable";
constexpr size_t kRemoteConfigPayloadBufferSize = 32;

constexpr uint8_t kWaterSensorRomCode[8] = {
    0x28, 0x33, 0x38, 0x44, 0x05, 0x00, 0x00, 0xCB,
};

constexpr SensorManagerConfig kSensorManagerConfig = {
    33,
    2000,
    12,
    1,
    {
        {
            true,
            {0x28, 0x33, 0x38, 0x44, 0x05, 0x00, 0x00, 0xCB},
            "Water sensor",
        },
    },
};

constexpr OledStatusDisplayConfig kOledStatusDisplayConfig = {
    32,
    27,
    128,
    32,
    0x3C,
    0x3D,
    400000,
};

FanDriver fanDriver;
RpmMonitor rpmMonitor;
FaultMonitor faultMonitor;
SensorManager sensorManager(kSensorManagerConfig);
MqttTelemetry mqttTelemetry;
OledStatusDisplay oledStatusDisplay(kOledStatusDisplayConfig);
OtaUploadServer otaUploadServer;
Preferences preferences;
ControlConfig runtimeControlConfig = kDefaultControlConfig;
ControlSnapshot lastControlSnapshot = {};
FaultMonitorSnapshot lastFaultSnapshot = {};
FaultPolicySnapshot lastFaultPolicySnapshot = {};
OtaTelemetrySnapshot otaTelemetrySnapshot = {
    false,
    "disabled",
    "OTA upload disabled.",
    kFirmwareVersion,
    kUnavailableText,
    kUnavailableText,
};
RemoteConfigStatus remoteConfigStatus = {};
uint32_t lastDiagnosticsMs = 0;
float requestedTargetTemperatureC = kDefaultControlConfig.defaultTargetTemperatureC;
bool hasConfiguredTargetTemperature = false;
bool preferencesReady = false;
bool lastFaultSnapshotValid = false;
bool telemetryPublishRequested = false;
char serialCommandBuffer[kSerialCommandBufferSize] = {};
size_t serialCommandLength = 0;
char mqttNetworkIpBuffer[kNetworkIpBufferSize] = "unavailable";
char mqttOtaUploadUrlBuffer[kOtaUploadUrlBufferSize] = "unavailable";
struct TelemetryEventState {
  ControlMode controlMode;
  uint8_t fanPwmPercent;
  bool fanFault;
  AlarmCode alarmCode;
  FaultSeverity faultSeverity;
  FaultResponse faultResponse;
  bool waterSensorOk;
  bool coolingDegraded;
  bool serviceRequired;
};
TelemetryEventState lastPublishedTelemetryEventState = {};
bool lastPublishedTelemetryEventStateValid = false;

TelemetryEventState buildTelemetryEventState(const ControlSnapshot& controlSnapshot,
                                             const FaultMonitorSnapshot& faultSnapshot,
                                             const FaultPolicySnapshot& policySnapshot) {
  return {
      controlSnapshot.mode,
      controlSnapshot.finalPwmPercent,
      faultSnapshot.faultLatched,
      policySnapshot.alarmCode,
      policySnapshot.severity,
      policySnapshot.response,
      policySnapshot.waterSensorOk,
      policySnapshot.coolingDegraded,
      policySnapshot.serviceRequired,
  };
}

bool telemetryEventStateEquals(const TelemetryEventState& lhs,
                               const TelemetryEventState& rhs) {
  return lhs.controlMode == rhs.controlMode &&
         lhs.fanPwmPercent == rhs.fanPwmPercent && lhs.fanFault == rhs.fanFault &&
         lhs.alarmCode == rhs.alarmCode &&
         lhs.faultSeverity == rhs.faultSeverity &&
         lhs.faultResponse == rhs.faultResponse &&
         lhs.waterSensorOk == rhs.waterSensorOk &&
         lhs.coolingDegraded == rhs.coolingDegraded &&
         lhs.serviceRequired == rhs.serviceRequired;
}

void printHelp() {
  Serial.println("Serial commands:");
  Serial.println("  status        -> print diagnostics immediately");
  Serial.println("  target <c>    -> set target water temperature in C");
  Serial.println("  default       -> reset target temperature to default 23.0 C");
  Serial.println("  control       -> print current hysteresis and quiet-cooling defaults");
  Serial.println("  faults        -> print current fault-policy defaults");
  Serial.println("  network       -> print Wi-Fi/MQTT telemetry status");
  Serial.println("  publish       -> publish telemetry immediately when MQTT is connected");
  Serial.println("  ota status    -> print OTA upload status");
  Serial.println("  ota enable    -> open temporary OTA .bin upload window");
  Serial.println("  ota cancel    -> close OTA upload window");
  Serial.println("  help          -> show this help");
  Serial.println();
}

void printCoreVersion() {
  Serial.print("Firmware: ");
  Serial.print(kFirmwareName);
  Serial.print(" ");
  Serial.println(kFirmwareVersion);

  Serial.print("ESP32 Arduino core: ");
  Serial.print(ESP_ARDUINO_VERSION_MAJOR);
  Serial.print(".");
  Serial.print(ESP_ARDUINO_VERSION_MINOR);
  Serial.print(".");
  Serial.println(ESP_ARDUINO_VERSION_PATCH);
}

void printConfiguredRom(const char* label, const uint8_t romCode[8]) {
  Serial.print(label);
  for (size_t i = 0; i < 8; ++i) {
    if (romCode[i] < 0x10) {
      Serial.print('0');
    }
    Serial.print(romCode[i], HEX);
  }
  Serial.println();
}

void printCurveSummary() {
  Serial.println("Measured production fan curve:");

  const FanCurvePoint* curve = FanCurve::points();
  for (size_t i = 0; i < FanCurve::pointCount(); ++i) {
    Serial.print("  ");
    Serial.print(curve[i].pwmPercent);
    Serial.print("% -> ");
    Serial.print(curve[i].rpm);
    Serial.println(" RPM");
  }

  Serial.println();
  Serial.print("Start PWM: ");
  Serial.print(FanCurve::kStartPwmPercent);
  Serial.println("%");

  Serial.print("Minimum hold PWM: ");
  Serial.print(FanCurve::kMinimumHoldPwmPercent);
  Serial.println("%");

  Serial.print("Startup plausibility tolerance: +/-");
  Serial.print(FanCurve::kPlausibilityTolerancePercent);
  Serial.println("%");
}

bool beginPreferences() {
  preferencesReady = preferences.begin(kPreferencesNamespace, false);
  return preferencesReady;
}

void syncOtaTelemetrySnapshot() {
  otaTelemetrySnapshot.active = otaUploadServer.active();
  otaTelemetrySnapshot.stateLabel = otaUploadServer.statusLabel();
  otaTelemetrySnapshot.lastMessage = otaUploadServer.lastMessage();
  otaTelemetrySnapshot.firmwareVersion = kFirmwareVersion;

  if (WiFi.status() == WL_CONNECTED) {
    const IPAddress wifiIp = WiFi.localIP();
    snprintf(mqttNetworkIpBuffer,
             sizeof(mqttNetworkIpBuffer),
             "%u.%u.%u.%u",
             wifiIp[0],
             wifiIp[1],
             wifiIp[2],
             wifiIp[3]);
  } else {
    snprintf(mqttNetworkIpBuffer, sizeof(mqttNetworkIpBuffer), "%s", kUnavailableText);
  }

  otaTelemetrySnapshot.networkIp = mqttNetworkIpBuffer;

  if (otaUploadServer.active() && WiFi.status() == WL_CONNECTED) {
    snprintf(mqttOtaUploadUrlBuffer,
             sizeof(mqttOtaUploadUrlBuffer),
             "http://%s/update",
             mqttNetworkIpBuffer);
  } else {
    snprintf(mqttOtaUploadUrlBuffer,
             sizeof(mqttOtaUploadUrlBuffer),
             "%s",
             kUnavailableText);
  }

  otaTelemetrySnapshot.uploadUrl = mqttOtaUploadUrlBuffer;
}

void requestTelemetryPublish() {
  telemetryPublishRequested = true;
}

void markTelemetryPublishSuccessful(const ControlSnapshot& controlSnapshot,
                                    const FaultMonitorSnapshot& faultSnapshot,
                                    const FaultPolicySnapshot& policySnapshot) {
  lastPublishedTelemetryEventState =
      buildTelemetryEventState(controlSnapshot, faultSnapshot, policySnapshot);
  lastPublishedTelemetryEventStateValid = true;
  telemetryPublishRequested = false;
}

void setRemoteConfigStatus(bool accepted, const char* key, const char* detail) {
  remoteConfigStatus.lastCommandSeen = true;
  remoteConfigStatus.lastCommandAccepted = accepted;

  if (accepted) {
    ++remoteConfigStatus.acceptedCount;
  } else {
    ++remoteConfigStatus.rejectedCount;
  }

  snprintf(remoteConfigStatus.lastKey,
           sizeof(remoteConfigStatus.lastKey),
           "%s",
           key != nullptr ? key : "unknown");
  snprintf(remoteConfigStatus.lastDetail,
           sizeof(remoteConfigStatus.lastDetail),
           "%s",
           detail != nullptr ? detail : "none");
  requestTelemetryPublish();
}

void clearPersistedTargetTemperature() {
  if (!preferencesReady) {
    return;
  }

  preferences.remove(kKeyHasCustomTarget);
  preferences.remove(kKeyTargetTemperature);
}

void clearPersistedControlConfig() {
  if (!preferencesReady) {
    return;
  }

  preferences.remove(kKeyCoolingOnDelta);
  preferences.remove(kKeyCoolingOffDelta);
  preferences.remove(kKeyHighCoolingDelta);
  preferences.remove(kKeyFanLowPwm);
  preferences.remove(kKeyFanHighPwm);
}

void persistTargetTemperature(float targetTemperatureC) {
  if (!preferencesReady) {
    return;
  }

  preferences.putBool(kKeyHasCustomTarget, true);
  preferences.putFloat(kKeyTargetTemperature, targetTemperatureC);
}

void persistControlConfig(const ControlConfig& config) {
  if (!preferencesReady) {
    return;
  }

  preferences.putFloat(kKeyCoolingOnDelta, config.coolingOnDeltaC);
  preferences.putFloat(kKeyCoolingOffDelta, config.coolingOffDeltaC);
  preferences.putFloat(kKeyHighCoolingDelta, config.highCoolingDeltaC);
  preferences.putUChar(kKeyFanLowPwm, config.fanLowPwmPercent);
  preferences.putUChar(kKeyFanHighPwm, config.fanHighPwmPercent);
}

const char* validateControlConfigDetail(const ControlConfig& config) {
  if (!isfinite(config.coolingOnDeltaC) ||
      config.coolingOnDeltaC < config.minimumCoolingOnDeltaC ||
      config.coolingOnDeltaC > config.maximumCoolingOnDeltaC ||
      config.coolingOnDeltaC <= 0.0f) {
    return "cooling_on_delta_c out of allowed range";
  }

  if (!isfinite(config.coolingOffDeltaC) ||
      config.coolingOffDeltaC < config.minimumCoolingOffDeltaC ||
      config.coolingOffDeltaC > config.maximumCoolingOffDeltaC ||
      config.coolingOffDeltaC >= 0.0f) {
    return "cooling_off_delta_c out of allowed range";
  }

  if (!isfinite(config.highCoolingDeltaC) ||
      config.highCoolingDeltaC < config.minimumHighCoolingDeltaC ||
      config.highCoolingDeltaC > config.maximumHighCoolingDeltaC) {
    return "high_cooling_delta_c out of allowed range";
  }

  if (config.highCoolingDeltaC <= config.coolingOnDeltaC ||
      (config.highCoolingDeltaC - config.coolingOnDeltaC) < 0.1f) {
    return "high_cooling_delta_c must exceed cooling_on_delta_c";
  }

  if (config.fanLowPwmPercent < config.minimumFanLowPwmPercent ||
      config.fanLowPwmPercent > config.maximumFanLowPwmPercent) {
    return "fan_low_pwm_percent out of allowed range";
  }

  if (config.fanHighPwmPercent < config.minimumFanHighPwmPercent ||
      config.fanHighPwmPercent > config.maximumFanHighPwmPercent) {
    return "fan_high_pwm_percent out of allowed range";
  }

  if (config.fanHighPwmPercent <= config.fanLowPwmPercent) {
    return "fan_high_pwm_percent must exceed fan_low_pwm_percent";
  }

  return nullptr;
}

bool applyRuntimeControlConfig(const ControlConfig& candidate, const char** detailOut) {
  if (!ControlEngine::isControlConfigValid(candidate)) {
    if (detailOut != nullptr) {
      *detailOut = validateControlConfigDetail(candidate);
    }
    return false;
  }

  runtimeControlConfig = candidate;
  persistControlConfig(runtimeControlConfig);
  requestTelemetryPublish();

  if (detailOut != nullptr) {
    *detailOut = "persisted";
  }
  return true;
}

void loadPersistedTargetTemperature() {
  requestedTargetTemperatureC = kDefaultControlConfig.defaultTargetTemperatureC;
  hasConfiguredTargetTemperature = false;

  if (!preferencesReady) {
    return;
  }

  const bool hasStoredTarget = preferences.getBool(kKeyHasCustomTarget, false);
  const float storedTargetTemperatureC =
      preferences.getFloat(kKeyTargetTemperature,
                           kDefaultControlConfig.defaultTargetTemperatureC);

  if (hasStoredTarget &&
      ControlEngine::isTargetTemperatureValid(storedTargetTemperatureC)) {
    requestedTargetTemperatureC = storedTargetTemperatureC;
    hasConfiguredTargetTemperature = true;
    return;
  }

  if (hasStoredTarget) {
    clearPersistedTargetTemperature();
  }
}

void initializeRuntimeControlConfig() {
  runtimeControlConfig = kDefaultControlConfig;

  if (!preferencesReady) {
    return;
  }

  ControlConfig candidate = runtimeControlConfig;
  candidate.coolingOnDeltaC =
      preferences.getFloat(kKeyCoolingOnDelta, kDefaultControlConfig.coolingOnDeltaC);
  candidate.coolingOffDeltaC =
      preferences.getFloat(kKeyCoolingOffDelta, kDefaultControlConfig.coolingOffDeltaC);
  candidate.highCoolingDeltaC =
      preferences.getFloat(kKeyHighCoolingDelta, kDefaultControlConfig.highCoolingDeltaC);
  candidate.fanLowPwmPercent =
      preferences.getUChar(kKeyFanLowPwm, kDefaultControlConfig.fanLowPwmPercent);
  candidate.fanHighPwmPercent =
      preferences.getUChar(kKeyFanHighPwm, kDefaultControlConfig.fanHighPwmPercent);

  if (!ControlEngine::isControlConfigValid(candidate)) {
    clearPersistedControlConfig();
    return;
  }

  runtimeControlConfig = candidate;
}

void printTemperatureLine(const char* label, float value) {
  Serial.print(label);
  DisplayFormat::printTemperatureC(Serial, value);
  Serial.println(" C");
}

void printTrackedSensorDetails(const SensorSnapshot& sensorSnapshot, uint32_t nowMs) {
  for (size_t trackedIndex = 0;
       trackedIndex < kSensorManagerConfig.trackedSensorCount;
       ++trackedIndex) {
    const TrackedSensorSnapshot& tracked =
        sensorSnapshot.trackedSensors[trackedIndex];
    char sensorAddress[kSensorAddressBufferSize] = {};
    sensorManager.formatTrackedAddress(trackedIndex, sensorAddress, sizeof(sensorAddress));

    Serial.print("  ");
    Serial.print(kSensorManagerConfig.trackedSensors[trackedIndex].sensorLabel);
    Serial.print(" matched: ");
    Serial.println(tracked.configuredAddressMatched ? "yes" : "no");

    Serial.print("  ");
    Serial.print(kSensorManagerConfig.trackedSensors[trackedIndex].sensorLabel);
    Serial.print(" ROM: ");
    Serial.println(sensorAddress);

    Serial.print("  ");
    Serial.print(kSensorManagerConfig.trackedSensors[trackedIndex].sensorLabel);
    Serial.print(" sample valid: ");
    Serial.println(tracked.sampleValid ? "yes" : "no");

    Serial.print("  ");
    Serial.print(kSensorManagerConfig.trackedSensors[trackedIndex].sensorLabel);
    Serial.print(" power mode: ");
    Serial.println(tracked.externallyPowered ? "external" : "parasite/unknown");

    Serial.print("  ");
    Serial.print(kSensorManagerConfig.trackedSensors[trackedIndex].sensorLabel);
    Serial.print(" temperature: ");
    if (tracked.sampleValid) {
      DisplayFormat::printTemperatureC(Serial, tracked.temperatureC);
      Serial.println(" C");
    } else {
      Serial.println("unavailable");
    }

    Serial.print("  ");
    Serial.print(kSensorManagerConfig.trackedSensors[trackedIndex].sensorLabel);
    Serial.print(" sample age: ");
    if (tracked.sampleValid) {
      Serial.print(nowMs - tracked.lastSampleMs);
      Serial.println(" ms");
    } else {
      Serial.println("n/a");
    }
  }
}
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
void loop() {
  const uint32_t nowMs = millis();
  processSerialInput();

  sensorManager.update(nowMs);
  const SensorSnapshot& sensorSnapshot = sensorManager.snapshot();
  lastControlSnapshot =
      ControlEngine::compute(buildControlInputs(sensorSnapshot), runtimeControlConfig);

  fanDriver.setCommandedPwmPercent(lastControlSnapshot.finalPwmPercent, nowMs);
  fanDriver.update(nowMs);
  rpmMonitor.update(nowMs);
  mqttTelemetry.update(nowMs);
  otaUploadServer.update(nowMs);
  syncOtaTelemetrySnapshot();
  oledStatusDisplay.update(nowMs, sensorSnapshot, lastFaultSnapshotValid, lastFaultPolicySnapshot);

  if (telemetryPublishRequested && lastFaultSnapshotValid) {
    const bool published = mqttTelemetry.publishTelemetry(nowMs,
                                                          lastControlSnapshot,
                                                          runtimeControlConfig,
                                                          otaTelemetrySnapshot,
                                                          lastFaultSnapshot,
                                                          lastFaultPolicySnapshot,
                                                          remoteConfigStatus,
                                                          true);
    if (published) {
      markTelemetryPublishSuccessful(lastControlSnapshot,
                                     lastFaultSnapshot,
                                     lastFaultPolicySnapshot);
    }
  }

  if (nowMs - lastDiagnosticsMs < kDiagnosticsIntervalMs) {
    return;
  }

  lastDiagnosticsMs = nowMs;

  lastFaultSnapshot =
      faultMonitor.evaluate(fanDriver.appliedPwmPercent(), rpmMonitor.rpm(), nowMs);
  lastFaultPolicySnapshot = FaultPolicy::evaluate(lastControlSnapshot, lastFaultSnapshot);
  lastFaultSnapshotValid = true;

  const TelemetryEventState currentTelemetryEventState =
      buildTelemetryEventState(lastControlSnapshot,
                               lastFaultSnapshot,
                               lastFaultPolicySnapshot);
  if (lastPublishedTelemetryEventStateValid &&
      !telemetryEventStateEquals(currentTelemetryEventState,
                                 lastPublishedTelemetryEventState)) {
    requestTelemetryPublish();
  }

  printDiagnostics(lastFaultSnapshot,
                   lastFaultPolicySnapshot,
                   rpmMonitor.sampleAgeMs(nowMs),
                   nowMs);
  const bool published = mqttTelemetry.publishTelemetry(nowMs,
                                                        lastControlSnapshot,
                                                        runtimeControlConfig,
                                                        otaTelemetrySnapshot,
                                                        lastFaultSnapshot,
                                                        lastFaultPolicySnapshot,
                                                        remoteConfigStatus,
                                                        false);
  if (published) {
    markTelemetryPublishSuccessful(lastControlSnapshot,
                                   lastFaultSnapshot,
                                   lastFaultPolicySnapshot);
  }
}

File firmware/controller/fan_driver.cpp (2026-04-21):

/**
 * @file fan_driver.cpp
 * @brief Implements ESP32 LEDC fan PWM output control.
 */

#include "fan_driver.h"

FanDriver::FanDriver(const FanDriverConfig& config)
    : config_(config),
      commandedPwmPercent_(0),
      appliedPwmPercent_(0),
      startBoostActive_(false),
      startBoostUntilMs_(0),
      initialized_(false) {}

bool FanDriver::begin() {
  initialized_ = ledcAttach(config_.pwmPin, config_.pwmFrequencyHz,
                            config_.pwmResolutionBits);
  if (!initialized_) {
    return false;
  }

  applyPwmPercent(0);
  return true;
}

void FanDriver::setCommandedPwmPercent(uint8_t pwmPercent, uint32_t nowMs) {
  pwmPercent = min<uint8_t>(pwmPercent, 100);

  if (pwmPercent == commandedPwmPercent_) {
    return;
  }

  const bool wasStopped = commandedPwmPercent_ == 0 && appliedPwmPercent_ == 0;
  commandedPwmPercent_ = pwmPercent;

  if (commandedPwmPercent_ == 0) {
    startBoostActive_ = false;
    startBoostUntilMs_ = 0;
    applyPwmPercent(0);
    return;
  }

  if (wasStopped && commandedPwmPercent_ < config_.startBoostPwmPercent) {
    startBoostActive_ = true;
    startBoostUntilMs_ = nowMs + config_.startBoostDurationMs;
    applyPwmPercent(config_.startBoostPwmPercent);
    return;
  }

  startBoostActive_ = false;
  startBoostUntilMs_ = 0;
  applyPwmPercent(commandedPwmPercent_);
}

void FanDriver::update(uint32_t nowMs) {
  if (!startBoostActive_) {
    return;
  }

  if ((int32_t)(nowMs - startBoostUntilMs_) >= 0) {
    startBoostActive_ = false;
    startBoostUntilMs_ = 0;
    applyPwmPercent(commandedPwmPercent_);
  }
}

uint8_t FanDriver::commandedPwmPercent() const {
  return commandedPwmPercent_;
}

uint8_t FanDriver::appliedPwmPercent() const {
  return appliedPwmPercent_;
}

bool FanDriver::isStartBoostActive() const {
  return startBoostActive_;
}

void FanDriver::applyPwmPercent(uint8_t pwmPercent) {
  pwmPercent = min<uint8_t>(pwmPercent, 100);
  appliedPwmPercent_ = pwmPercent;

  if (!initialized_) {
    return;
  }

  const uint32_t maxDuty = (1UL << config_.pwmResolutionBits) - 1UL;
  const uint32_t duty = (maxDuty * pwmPercent + 50UL) / 100UL;
  ledcWrite(config_.pwmPin, duty);
}

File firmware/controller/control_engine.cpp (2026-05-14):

/**
 * @file control_engine.cpp
 * @brief Implements temperature-based cooling PWM calculations.
 */

#include "control_engine.h"

#include <math.h>

namespace ControlEngine {

bool isTargetTemperatureValid(float targetTemperatureC, const ControlConfig& config) {
  return isfinite(targetTemperatureC) &&
         targetTemperatureC >= config.minimumTargetTemperatureC &&
         targetTemperatureC <= config.maximumTargetTemperatureC;
}

bool isControlConfigValid(const ControlConfig& config) {
  return isfinite(config.coolingOnDeltaC) &&
         config.coolingOnDeltaC >= config.minimumCoolingOnDeltaC &&
         config.coolingOnDeltaC <= config.maximumCoolingOnDeltaC &&
         isfinite(config.coolingOffDeltaC) &&
         config.coolingOffDeltaC >= config.minimumCoolingOffDeltaC &&
         config.coolingOffDeltaC <= config.maximumCoolingOffDeltaC &&
         config.coolingOffDeltaC < 0.0f &&
         config.coolingOnDeltaC > 0.0f &&
         isfinite(config.highCoolingDeltaC) &&
         config.highCoolingDeltaC >= config.minimumHighCoolingDeltaC &&
         config.highCoolingDeltaC <= config.maximumHighCoolingDeltaC &&
         config.highCoolingDeltaC > config.coolingOnDeltaC &&
         (config.highCoolingDeltaC - config.coolingOnDeltaC) >= 0.1f &&
         config.fanLowPwmPercent >= config.minimumFanLowPwmPercent &&
         config.fanLowPwmPercent <= config.maximumFanLowPwmPercent &&
         config.fanHighPwmPercent >= config.minimumFanHighPwmPercent &&
         config.fanHighPwmPercent <= config.maximumFanHighPwmPercent &&
         config.fanHighPwmPercent > config.fanLowPwmPercent;
}

float sanitizeTargetTemperature(float targetTemperatureC, const ControlConfig& config) {
  if (isTargetTemperatureValid(targetTemperatureC, config)) {
    return targetTemperatureC;
  }

  return config.defaultTargetTemperatureC;
}

ControlSnapshot compute(const ControlInputs& inputs, const ControlConfig& config) {
  const bool configuredTargetIsValid =
      inputs.hasConfiguredTargetTemperature &&
      isTargetTemperatureValid(inputs.requestedTargetTemperatureC, config);
  const float targetTemperatureC = configuredTargetIsValid
                                       ? inputs.requestedTargetTemperatureC
                                       : config.defaultTargetTemperatureC;
  const bool targetDefaulted = !configuredTargetIsValid;
  ControlSnapshot snapshot = {};
  snapshot.targetTemperatureC = targetTemperatureC;
  snapshot.targetDefaulted = targetDefaulted;
  snapshot.waterSensorValid = inputs.waterSensorValid && isfinite(inputs.waterTemperatureC);
  snapshot.waterTemperatureC =
      snapshot.waterSensorValid ? inputs.waterTemperatureC : NAN;

  if (!snapshot.waterSensorValid) {
    snapshot.waterDeltaC = NAN;
    snapshot.waterBasedPwmPercent = 0;
    snapshot.finalPwmPercent = config.fallbackPwmPercent;
    snapshot.mode = ControlMode::kWaterSensorFallback;
    return snapshot;
  }

  const float waterDeltaC = snapshot.waterTemperatureC - targetTemperatureC;
  ControlMode mode = inputs.previousMode;
  if (mode != ControlMode::kFanLow &&
      mode != ControlMode::kFanHigh &&
      mode != ControlMode::kFanOff) {
    mode = ControlMode::kFanOff;
  }

  if (mode == ControlMode::kFanHigh) {
    if (waterDeltaC < config.highCoolingDeltaC) {
      mode = ControlMode::kFanLow;
    }
  }

  if (mode == ControlMode::kFanLow) {
    if (waterDeltaC <= config.coolingOffDeltaC) {
      mode = ControlMode::kFanOff;
    } else if (waterDeltaC >= config.highCoolingDeltaC) {
      mode = ControlMode::kFanHigh;
    }
  } else if (mode == ControlMode::kFanOff) {
    if (waterDeltaC >= config.highCoolingDeltaC) {
      mode = ControlMode::kFanHigh;
    } else if (waterDeltaC >= config.coolingOnDeltaC) {
      mode = ControlMode::kFanLow;
    }
  }

  const uint8_t waterBasedPwmPercent =
      mode == ControlMode::kFanHigh
          ? config.fanHighPwmPercent
          : (mode == ControlMode::kFanLow ? config.fanLowPwmPercent : 0);

  snapshot.waterDeltaC = waterDeltaC;
  snapshot.waterBasedPwmPercent = waterBasedPwmPercent;
  snapshot.finalPwmPercent = snapshot.waterBasedPwmPercent;
  snapshot.mode = mode;
  return snapshot;
}

const char* modeLabel(ControlMode mode) {
  switch (mode) {
    case ControlMode::kFanOff:
      return "fan-off";
    case ControlMode::kFanLow:
      return "fan-low";
    case ControlMode::kFanHigh:
      return "fan-high";
    case ControlMode::kWaterSensorFallback:
      return "water-sensor-fallback";
    default:
      return "unknown";
  }
}

}  // namespace ControlEngine

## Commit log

2026-04-12 Document fan characterization results and capture logs
2026-04-12 Add visual fan curve chart
2026-04-12 Add DS18B20 water sensor bring-up
2026-04-14 Add water and air sensor bus bring-up
2026-04-14 Add first local water temperature control
2026-04-14 Rewrite README for current project milestone
2026-04-16 Add FHEM MQTT2 integration
    [aquarium-cooling-mqtt2-device.cfg]
2026-04-20 Release firmware 0.1.0
    [2026-04-16-aquarium-2h-fhem-export.csv, aquarium-controller-enclosure.scad]
2026-04-20 docs: archive 28h aquarium live test
    [2026-04-16-to-2026-04-17-aquarium-28h-fhem-export.csv]
2026-04-21 Refine Arduino Doxygen overview
2026-04-26 Add BIN-only OTA workflow for the controller
    - add a manually enabled BIN-only OTA upload workflow for the ESP32 controller
    - harden OTA validation around firmware identity, version progression, incomplete uploads, and rollback confirmation
    - update README, changelog, design metadata, and FSD to reflect the implemented OTA workflow and repository build-artifact policy
2026-04-26 feat: add mqtt remote configuration and rounded temperature output (#10)
    [aquarium-cooling-mqtt2-device.cfg]
2026-04-27 feat: add mqtt-controlled ota maintenance window (#12)
    [aquarium-cooling-mqtt2-device.cfg]
2026-05-01 Release firmware 0.1.4 with water-only control and OTA endpoint discovery (#13)
    * feat: simplify controller to water-only hysteresis
    * chore: bump firmware version for ota rollout
    * release: publish firmware 0.1.4
    [aquarium-cooling-mqtt2-device.cfg]
2026-05-01 Stabilize Arduino CLI build workflow
2026-05-02 tune: raise fixed cooling stage to 22 percent
    [controller.ino]
2026-05-14 feat: add staged water-only MQTT control configuration
    * feat: add staged water-only mqtt control config
    * docs: add concrete fhem dblog profile
    * Improve FHEM device visuals for firmware 0.1.6
    * Fix Doxygen param docs for MQTT telemetry
    * docs: finalize staged control documentation
    * docs: refresh doxygen mainpage for staged control
    [2026-04-30-to-2026-05-02-aquarium-44h-water-only-18pct-fhem-export.csv, 2026-05-02-to-2026-05-13-aquarium-11d-water-only-22pct-fhem-export.csv, aquarium-coolin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]
2026-06-13 docs: archive 30-day staged control live test
    [2026-05-14-to-2026-06-13-aquarium-30d-staged-control-tuning-fhem-export.csv]
2026-06-13 feat: promote 45/60 staged cooling defaults
2026-06-13 Add canonical OTA workflow and MQTT cadence updates
    [aquarium-cooling-mqtt2-device.cfg]
2026-06-13 docs: align FHEM logging guidance with field profile
    [aquarium-cooling-mqtt2-device.cfg]
2026-06-14 Prepare release 0.2.0
    [aquarium-cooling-mqtt2-device.cfg]
